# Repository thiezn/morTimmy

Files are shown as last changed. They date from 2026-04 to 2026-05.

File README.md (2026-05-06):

# mortimmy

`mortimmy` is a Rust robotics workspace for a small rover split across two runtime environments:

- `firmware/rp2350` for deterministic embedded control across two RP2350 board images: a motion-controller image for the Pimoroni Pico LiPo 2 and an audio-controller image for the Pico 2 W + Pico Audio Pack
- `host/mortimmy` for Raspberry Pi or macOS orchestration, transport bridging, telemetry, audio routing, and future camera control

The current hardware is:

- Raspberry Pi 3B V1.2
- Pimoroni Pico 2 W with Pico Audio Pack
- Pimoroni Pico LiPo 2
- Liquid Crystal Display LCM1602C V2.1
- 2x HC-SR04 ultrasonic ranger
- Adafruit 4-channel I2C-safe Bi-directional Logic Level Converter - BSS138
- Trellis M4 4x4 keypad and LED matrix

## Hardware

| Component | Version / Model | Purpose |
| --- | --- | --- |
| Raspberry Pi | 3B V1.2 | Main host computer running the daemon, USB device orchestration, telemetry, and higher-level coordination |
| Motion controller | Pimoroni Pico LiPo 2 (RP2350B) | USB-connected real-time controller for motors, sensors, the LCD status display, and future servo logic |
| Audio controller | Pico 2 W + Pico Audio Pack | USB-connected audio playback controller for the DAC and amp-enable path |
| Audio add-on | Pimoroni Pico Audio Pack | I2S DAC and headphone / line-out hardware mounted on the Pico 2 W |
| Character display | LCM1602C V2.1 | 16x2 local status display driven in 4-bit mode from the motion-controller Pico |
| Ultrasonic sensors | 2x HC-SR04 | Forward-left and forward-right distance measurement for obstacle awareness |
| Motor drivers | 2x L298N dual H-bridge | Drive four wheel motors from the motion controller GPIO |
| Wheel motors | 4x DC gear motors | Rover propulsion |
| Power regulator | UBEC / buck, 5 V 3 A | Regulates battery voltage down to the Raspberry Pi supply rail |
| Battery pack | 2x 18650, 2S | Main energy source for the rover |
| Keypad / LEDs | Trellis M4 4x4 | Future local input and status LED surface |
| 4-channel I2C-safe Bi-directional Logic Level Converter - BSS138 | Level shifting for HC-SR04 TRIG/ECHO wiring and future I2C peripherals |

Shared crates under `crates/` define the core types, driver traits, and the wire protocol used across both sides. The protocol uses `postcard` for serialization and a COBS-framed transport with CRC16 integrity checks so the same message contract can move over USB CDC, UART, and recorded capture files.

For the current ultrasonic path, the Adafruit BSS138 board should be treated as a four-channel signal translator, not as a power supply. It needs `3V3`, `5V`, and `GND` connected as reference rails, then one channel for `TRIG` and one for `ECHO` if you want a conservative 3.3 V to 5 V interface. That means one board cleanly supports two HC-SR04 modules; a third sensor only fits if you accept module-dependent direct 3.3 V triggering and reserve the board channels for `ECHO` only.

## Firmware Targets

The embedded workspace keeps one RP2350 crate and composes board-specific images with feature flags instead of cloning a second firmware crate. Each image owns its board profile, pin map, target directory, and deployment metadata.

| Deploy target | Board | Cargo feature | Target dir | Current scope |
| --- | --- | --- | --- | --- |
| `motion-controller` | Pimoroni Pico LiPo 2 | `board-motion-controller` | `target/mortimmy-rp2350-motion-controller` | USB CDC transport, L298N motor drive, HC-SR04 ranging, LCD1602 bring-up on GP20/GP21/GP22/GP26/GP27/GP28 |
| `audio-controller` | Pico 2 W + Pico Audio Pack | `board-audio-controller` | `target/mortimmy-rp2350-audio-controller` | USB CDC transport, Audio Pack bring-up seam on GP9-GP11 plus optional GP29 amp enable |

`mortimmy-tools deploy firmware ...` selects these metadata blocks with `--target motion-controller` or `--target audio-controller`. The CLI still defaults to `motion-controller` for backwards compatibility.

Detailed architecture notes live in [docs/src/architecture/architecture.md](docs/src/architecture/architecture.md). Protocol-specific notes live in [docs/src/architecture/protocol.md](docs/src/architecture/protocol.md). Open follow-up work lives in [TODO.md](TODO.md).

## Current Scope

The workspace now contains a compileable control-plane scaffold with test and tooling support:

- `mortimmy-core` defines shared units, limits, modes, and error types.
- `mortimmy-protocol` defines the postcard schema, typed control and telemetry messages, CRC16 checks, and a stream-oriented COBS frame decoder sized for the current audio-forwarding contract.
- `mortimmy-drivers` defines hardware-facing traits for motors, servos, ultrasonic sensors, audio output, and Trellis input/LED control.
- `mortimmy-rp2350` is the active embedded crate for both RP2350 controller boards using `embassy-rp`, `embassy-usb`, and `panic-probe`; it now splits board-owned runtime wiring by target while keeping one shared scaffold, protocol bridge, and deploy metadata surface.
- `mortimmy` provides `start` and `config` subcommands backed by a nested `config.toml` layout for serial, websocket, telemetry, audio, camera, and logging settings, and the `start` path now runs a keyboard-driven brain loop against either the loopback Pico scaffold or future live transports.
- `mortimmy-tools` can inspect and replay captured framed protocol streams, build host artifacts, and deploy RP2350 firmware through BOOTSEL or probe-rs workflows.
- `mortimmy-integration-test` provides the root integration harness for protocol roundtrips and future live hardware smoke tests.

## Workspace Layout

```text
.
├── Cargo.toml
├── README.md
├── TODO.md
├── crates/
│   ├── core/
│   ├── drivers/
│   └── protocol/
├── docs/
│   └── src/
│       └── architecture/
├── firmware/
│   └── rp2350/
├── host/
│   ├── mortimmy/
│   └── tools/
├── integration_test/
└── scripts/
```

## Prerequisites

- Rust toolchain from [rust-toolchain.toml](rust-toolchain.toml)
- `cargo`
- For docs: `mdbook` and `mdbook-mermaid`
- For embedded flashing and debugging: `cargo install probe-rs-tools --locked`
- For UF2 generation and BOOTSEL uploads: `cargo install elf2uf2-rs --locked`
- For BOOTSEL uploads over the RP2350 picoboot interface on macOS: `brew install picotool`

The pinned toolchain includes `thumbv8m.main-none-eabihf`, so a fresh `rustup` install is enough to build the active embedded target.

During development, you can invoke the deployment CLI directly from the workspace with `cargo run -p mortimmy-tools -- ...`. If you want a standalone binary on your `PATH`, install it from this checkout with `cargo install --path host/tools`.

## Build, Test, And Lint

Build the whole workspace:

```bash
cargo check --workspace
```

Validate both embedded images explicitly:

```bash
cargo build -p mortimmy-rp2350 --target thumbv8m.main-none-eabihf --no-default-features --features board-motion-controller --target-dir target/mortimmy-rp2350-motion-controller
cargo build -p mortimmy-rp2350 --target thumbv8m.main-none-eabihf --no-default-features --features board-audio-controller --target-dir target/mortimmy-rp2350-audio-controller
```

Or drive the same builds through the deployment metadata owned by the firmware crate:

```bash
cargo run -p mortimmy-tools -- deploy firmware build --target motion-controller
cargo run -p mortimmy-tools -- deploy firmware build --target audio-controller
```

Run tests and lints:

```bash
cargo test --workspace
cargo clippy --workspace --all-targets
```

Build the documentation site:

```bash
mdbook build docs
```

Optional coverage report:

```bash
./scripts/coverage.sh
./scripts/coverage.sh --html
```

## Firmware Bring-Up On macOS

The current RP2350 firmware can be smoke-tested without any attached peripherals. On the embedded target each image now starts the same Embassy USB CDC protocol bridge, then hands off to a board-specific runtime module for the actual pin map and peripheral ownership.

The motion-controller image owns the Pico LiPo 2 motor, ultrasonic, and LCD wiring. The audio-controller image now only reserves the Pico Audio Pack control pins and exposes the seam where the RP2350 I2S transport will be wired in next.

The shared protocol is now exercised inside the firmware crate as well: desired-state, parameter, audio, Trellis LED, status, and ping commands are applied to the firmware scaffold under unit tests, and the default audio chunk size is aligned across host planning, wire payload sizing, and firmware buffering.

Validate the firmware locally before touching hardware:

```bash
cargo test -p mortimmy-rp2350
cargo run -p mortimmy-tools -- deploy firmware uf2 --target motion-controller
cargo run -p mortimmy-tools -- deploy firmware uf2 --target audio-controller
```

Upload over plain USB with the Pico in BOOTSEL mode:

1. Hold the board's `BOOTSEL` button while connecting USB-C.
2. Wait for either a BOOTSEL volume such as `RP2350` or `RPI-RP2` to appear, or for `picotool info` to list an RP2350 BOOTSEL device.
3. Run:

```bash
cargo run -p mortimmy-tools -- deploy firmware uf2-deploy --target motion-controller
```

Swap `--target audio-controller` when you are working with the Pico 2 W image.

If `picotool` is installed, `mortimmy-tools deploy firmware uf2-deploy` prefers `picotool load -v -x -t uf2` and reboots the board directly. This is the recommended macOS path because mass-storage copies to the BOOTSEL volume have hung behind `storagekitd` on this machine. The tool falls back to copying `NEW.UF2` only when `picotool` cannot access the BOOTSEL interface.

This flow has been validated end to end on this machine. A successful BOOTSEL deploy reported `Loading into Flash ... 100%`, `Verifying Flash ... 100%`, `OK`, and `The device was rebooted to start the application.`

If the deploy command reports `Unable to find a board in BOOTSEL mode`, the board is not in BOOTSEL mode yet or neither the picoboot interface nor the BOOTSEL volume is visible to macOS. The tool now prints the exact BOOTSEL entry steps before exiting.

Flash and stream RTT logs through an SWD probe:

```bash
cargo run -p mortimmy-tools -- deploy firmware probe-list
cargo run -p mortimmy-tools -- deploy firmware flash --target motion-controller --probe-index 0
cargo run -p mortimmy-tools -- deploy firmware run --target motion-controller --probe-index 0
```

Use `--target audio-controller` with the same commands when debugging the Pico 2 W image.

The probe-based workflow uses the `probe-rs` chip name `RP235x`. A successful RTT session starts with a line like:

```text
boot board=Pimoroni Pico LiPo 2 mcu=RP2350B flash=16777216 psram=8388608 transport=usb-cdc mode=teleop audio=host-waveform-bridge chunk_samples=240 trellis=false ultrasonic=false battery=false
```

This path has now been validated on this machine with a Raspberry Pi Debug Probe after updating the probe firmware. `mortimmy-tools deploy firmware flash --probe-index 0 --verify` succeeds over SWD while the Pico LiPo 2 is not in BOOTSEL mode, so BOOTSEL is no longer required for normal flashing when the probe is attached.

If `mortimmy-tools deploy firmware run --probe-index 0` flashes successfully but shows no RTT or defmt output, rebuild with `DEFMT_LOG=info`. `defmt` filters logs at build time, and without that override the `info!` boot banner can be compiled out entirely. The provided VS Code build task below already sets `DEFMT_LOG=info` for you.

If `firmware-flash` reports `No debug probes were found`, attach an SWD-compatible debug probe or fall back to the BOOTSEL/UF2 path above.

After a successful BOOTSEL upload, the Pico should enumerate as a runtime USB CDC device such as `/dev/cu.usbmodem*` on macOS. That runtime enumeration path is implemented in firmware; regular live smoke coverage for the full host-to-device roundtrip remains tracked in `TODO.md`.

## Debug In VS Code

Install the VS Code extension `probe-rs.probe-rs-debugger` and keep `probe-rs` on your `PATH`.

This repo now ships a ready-to-use [launch.json](.vscode/launch.json) and [tasks.json](.vscode/tasks.json) for the motion-controller firmware. The default build task compiles the RP2350 ELF with `DEFMT_LOG=info` into the same `target/mortimmy-rp2350-motion-controller` directory used by the repo's deployment tooling. The audio-controller image uses the same crate and target triple, but it does not have a dedicated VS Code launch/task preset yet.

Typical flow:

1. Connect the Raspberry Pi Debug Probe to the Pico LiPo 2 over SWD.
2. Keep the Pico's normal USB connection attached if you also want the runtime CDC serial device on macOS.
3. In VS Code, run the default build task or press `F5` and choose `RP2350 Launch + RTT`.
4. Use `RP2350 Attach + RTT` when the firmware is already flashed and you want to attach without reflashing.

The launch configuration targets chip `RP235x`, uses `Swd`, flashes the ELF from `target/mortimmy-rp2350-motion-controller/thumbv8m.main-none-eabihf/debug/mortimmy-rp2350`, and enables RTT decoding for defmt channel 0. RTT output appears in the integrated terminal.

If you have more than one probe attached, add a `probe` field to [launch.json](.vscode/launch.json) using the `VID:PID:SERIAL` form shown by `cargo run -p mortimmy-tools -- deploy firmware probe-list`.

This repo does not currently ship a CMSIS-SVD file for RP235x, so the launch configuration omits `svdFile`. Source-level breakpoints, stepping, call stacks, locals, and defmt RTT logs still work without it.

## Run Locally On macOS

The host brain now supports both the `loopback` transport for local proofing and the `serial` transport for a live Pico USB CDC device. Both paths use the same routing, postcard codec, and CRC16 plus COBS framing.

`teleop` with zero drive is now the nominal stopped state. If the firmware link times out, the controller enters `fault`, resets to its safe failed state, and the host reasserts its last requested `teleop` or `autonomous` mode after reconnect.

Create or update a config file:

```bash
cargo run -p mortimmy -- config --config ./config.toml --print
```

Run the brain loop with keyboard input and the in-process Pico scaffold:

```bash
cargo run -p mortimmy -- start \
  --config ./tmp/brain-loopback.toml \
  --input-backend keyboard \
  --transport-backend loopback
```

Useful keyboard commands during bring-up:

```text
p | ping
x | stop
w | forward
s | reverse
a | left
d | right
t | teleop mode
u | autonomous mode (default servo-scan plan)
f | fault mode
q | quit
```

Switch the local keyboard to tank controls when you want per-tread input:

```bash
cargo run -p mortimmy -- start \
  --config ./tmp/brain-loopback.toml \
  --input-backend keyboard \
  --keyboard-drive-style tank \
  --transport-backend loopback
```

You can also press `m` while the session is running to toggle between `wasd` and `tank` driving. In tank mode, `w` and `s` control the left tread, `e` and `d` control the right tread, and `a` gives a left pivot shortcut by driving the left tread forward while reversing the right tread. To accept input from only one controller instead of letting the most recent controller win, pass `--controller-lock KIND:INSTANCE`, for example `--controller-lock keyboard:local`.

Websocket controllers are now live on the configured bind address as well. Each websocket client appears as its own `websocket:client-N` controller, so `--controller-lock websocket:client-1` will pin the brain to the first connected websocket client. Send JSON text frames such as:

```json
{"type":"control","drive":{"forward":1.0,"turn":0.0,"speed":300}}
{"type":"control","drive":null}
{"type":"command","command":"ping"}
{"type":"command","command":"teleop"}
```

`forward` and `turn` are normalized from `-1.0` to `1.0` and map onto the existing desired-state control path. Supported websocket commands are `ping`, `stop`, `teleop`, `autonomous`, `fault`, and `quit`.

This path has been validated on this machine with `p` followed by `q`; the host logged startup, encoded the ping command over the shared protocol, and received `telemetry pong: Pong` back from the firmware scaffold.

Run the same brain loop against a flashed Pico over USB CDC:

```bash
cargo run -p mortimmy -- start \
  --config ./tmp/brain-serial.toml \
  --input-backend keyboard \
  --transport-backend serial \
  --serial-device /dev/cu.usbmodem0001
```

For live hardware validation, `p` should return `telemetry pong: Pong`, holding `w` plus `a` should produce one combined desired-state control path, and `u` should switch the host into the built-in autonomous servo-scan plan until another mode is selected.

If you want to exercise the future camera seam, enable the optional `nokhwa` backend:

```bash
cargo run -p mortimmy --features camera-nokhwa -- start \
  --config ./config.toml \
  --serial-device /dev/tty.usbmodem0001 \
  --camera-enabled=true \
  --camera-backend nokhwa
```

Inspect or replay a captured protocol stream:

```bash
cargo run -p mortimmy-tools -- inspect ./captures/session.bin
cargo run -p mortimmy-tools -- replay ./captures/session.bin --dry-run
```

## Run On Raspberry Pi

The host daemon is intended to run directly on Raspberry Pi OS once the USB/serial bridge is wired to the firmware.

Build on the Pi:

```bash
cargo build -p mortimmy --release
```

Write or update the Pi config:

```bash
./target/release/mortimmy config --config ./config.toml \
  --serial-device /dev/ttyACM0 \
  --websocket-bind 0.0.0.0:9001 \
  --audio-enabled=true \
  --audio-backend firmware-bridge
```

Start the daemon:

```bash
./target/release/mortimmy start --config ./config.toml
```

Example config layout:

```toml
[serial]
device_path = "/dev/ttyACM0"
baud_rate = 115200

[websocket]
bind_address = "0.0.0.0:9001"

[telemetry]
publish_interval_ms = 100
queue_capacity = 256

[audio]
enabled = true
backend = "firmware-bridge"
sample_rate_hz = 24000
channels = 1
chunk_samples = 240
volume_percent = 100

[camera]
enabled = false
backend = "disabled"
device_index = 0
width = 640
height = 480
fps = 30

[logging]
level = "info"
no_color = false
```

## Integration Tests

The `integration_test` crate contains both portable protocol tests and ignored live-hardware smoke tests. Hardware tests are configured through the `MORTIMMY_HW_CONFIG` environment variable.

A checked-in bare-board sample lives at [integration_test/hardware.example.toml](integration_test/hardware.example.toml). It assumes no audio bridge or Trellis hardware is attached yet.

Example hardware test config:

```toml
serial_device = "/dev/ttyACM0"
baud_rate = 115200
timeout_ms = 2000
expect_audio_bridge = false
expect_trellis = false
```

Run the ignored live tests:

```bash
MORTIMMY_HW_CONFIG=./integration_test/hardware.example.toml cargo test -p mortimmy-integration-test -- --ignored
```

## Deployment CLI

The deployment surface now lives in `mortimmy-tools deploy`. The examples below use the installed binary name; if you are running straight from the workspace, prefix them with `cargo run -p mortimmy-tools --` instead.

Host workflows:

```bash
mortimmy-tools deploy host build
mortimmy-tools deploy host print-artifact
mortimmy-tools deploy host local-install --sudo
mortimmy-tools deploy host remote-copy --remote-host pi@raspberrypi.local
mortimmy-tools deploy host remote-install --remote-host pi@raspberrypi.local --sudo
```

Firmware workflows:

```bash
mortimmy-tools deploy firmware build --target motion-controller
mortimmy-tools deploy firmware build --target audio-controller
mortimmy-tools deploy firmware print-artifact --target audio-controller
mortimmy-tools deploy firmware uf2 --target audio-controller
mortimmy-tools deploy firmware uf2-deploy --target motion-controller
mortimmy-tools deploy firmware probe-list
mortimmy-tools deploy firmware flash --target motion-controller --probe-index 0
mortimmy-tools deploy firmware run --target motion-controller --probe-index 0
```

The most useful customization flags are:

- Global logging: `--log-level trace|debug|info|warn|error`, `--no-color`
- Host deployment: `--package`, `--bin`, `--profile`, `--install-dir`, `--remote-host`, `--remote-dir`
- Firmware build and UF2 packaging: `--target motion-controller|audio-controller`, `--profile`, `--output`
- Firmware probe workflows: `--probe-index`, `--protocol swd|jtag`, `--speed-khz`
- Firmware flashing behavior: `--chip-erase`, `--preverify`, `--verify`, `--restore-unwritten`, `--disable-double-buffering`

`mortimmy-tools deploy firmware uf2-deploy` prefers `picotool` when it can see the board in BOOTSEL mode and falls back to the mounted UF2 volume copy path only when the picoboot interface is unavailable. `mortimmy-tools deploy firmware run` currently delegates the monitor UX to `probe-rs run`, which preserves the existing defmt/RTT workflow while keeping the board-target selection inside the Rust deployment tool.

## Documentation

- Architecture: [docs/src/architecture/architecture.md](docs/src/architecture/architecture.md)
- Roadmap: [TODO.md](TODO.md)
- MdBook summary: [docs/src/SUMMARY.md](docs/src/SUMMARY.md)

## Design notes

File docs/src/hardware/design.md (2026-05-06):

# Hardware System Architecture and Power Design

## 1. System Architecture Overview

This robot is designed as a **layered hardware system**. Each layer has a clearly defined responsibility, explicit interfaces, and controlled dependencies. Power is treated as a first‑class subsystem rather than an afterthought.

### Layered Hardware Model

    Mechanical Structure
    └── Power System
        ├── High‑power actuation rails (motors)
        ├── Medium‑power actuation rails (servos)
        ├── Logic power rails (MCUs, SBCs, sensors)
    └── Compute & Control
        ├── Main processor (SBC / Raspberry Pi)
        ├── Real‑time controllers (microcontrollers)
    └── Interconnect
        ├── Power distribution
        ├── Data buses and signaling
    └── Peripherals
        ├── Motors
        ├── Servos
        ├── Sensors
        ├── Audio and UI components

Each layer may evolve independently as long as **power interfaces and signal contracts remain stable**.

## 2. Power Architecture

### Design Decision

The system uses **a single battery source with centralized power distribution**, implemented through a dedicated **Power Distribution Board (PDB)**

All primary system rails originate on this board.  
The only local conversion off-board is the Pico 2 onboard 3.3 V regulator, used only for control-board logic.

The control board feeds the Pico 2 at `VSYS` from `AUX_5V` through a reverse-blocking ideal-diode path. The Pi 3B still reaches the Pico over the Pico USB connector for programming and runtime communication.

### Power Topology

    Battery Pack (2S single source)
    │
    ├── Protected raw rail (`MOTOR_VM`)
    │   └── Two TB6612FNG motor-driver stages on the PDB
    │
    ├── Medium‑current rail (`SERVO_6V`)
    │   └── Servo connectors
    │
    └── Logic rails
        ├── `PI_5V` → Raspberry Pi
        ├── `AUX_5V` → Control board `VSYS` feed and 5 V loads
        ├── `DRV_3V3` → PDB-local TB6612 logic
        └── Pico `3V3` → Control-board MCU and level shifting

### Rail Separation Rationale

*   Motors generate electrical noise and large current spikes
*   Servos generate medium transient loads
*   Logic components require clean and stable voltage

Separating rails **prevents brown‑outs, resets, and signal corruption** while maintaining a shared reference ground.

## 3. Power Distribution Board (PDB)

### Role

The Power Distribution Board is the **electrical anchor** of the system.

It has no compute logic and performs no signaling functions beyond power delivery and monitoring.

### Core Responsibilities

*   Accept battery input
*   Provide reverse‑polarity and over‑current protection
*   Generate required voltage rails
*   Distribute power through dedicated connectors
*   Provide a central ground reference

### Typical Components on the PDB

*   Battery connector (JST-VH in the current board plan)
*   Main fuse
*   Master power switch
*   Reverse polarity protection (MOSFET or diode)
*   5.1 V buck converter for `PI_5V` and `AUX_5V`
*   6.0 V buck converter for `SERVO_6V`
*   Local 3.3 V regulator for TB6612FNG `VCC` and `STBY`
*   Two TB6612FNG stages on the PDB beside the wheel-motor connectors
*   Bulk capacitors near the battery entry, the 5.1 V rail, the 6.0 V rail, and each TB6612FNG stage
*   Measurement points for each rail
*   Ground plane with controlled high-current return paths and stitching vias around the driver region

## 4. System Architecture

                         ┌────────────────────┐
                         │    Battery Pack    │
                         └─────────┬──────────┘
                                   │
                        ┌──────────▼──────────┐
                        │ Power Distribution  │
                        │ Board (PDB)         │
                        │─────────────────────│
                        │ • Fuse              │
                        │ • Polarity protect  │
                        │ • TB6612FNG x2      │
                        │ • 6V Buck (Servos)  │
                        │ • 5.1V Buck         │
                        │ • DRV_3V3 Regulator │
                        │ • Central Ground    │
                        └───┬────────┬─────┬─┘
                            │        │     │
                    ┌───────▼──────┐ │     │
                    │ Control Board│ │     │
                    │ Pico + LCD + │ │     │
                    │ US + USB dev │ │     │
                    └──────────────┘ │     │
                                     │     │
                             ┌───────▼┐ ┌──▼─────────┐
                             │ Servos │ │ Raspberry  │
                             │ (6V)   │ │ Pi (5V)    │
                             └────────┘ └────────────┘

All components connect **inwards** to the power system rather than chaining power between devices.

## 5. Detailed Power Rail Schematic (Conceptual)

                    Battery (+)
                        │
                    [ Main Fuse ]
                        │
                   [ Master Switch ]
                        │
               [ Reverse Polarity Protection ]
                        │
                ┌────────┼──────────────┬──────────────┐
                │        │              │              │
          `MOTOR_VM`  [Buck 5.1V]   [Buck 6.0V]   [Reg 3.3V]
                │        │              │              │
         TB6612FNG x2  `PI_5V` +     Servo Rail    `DRV_3V3`
                    │       `AUX_5V`         │              │
            Wheel Motors  │            Servos      TB6612 VCC/STBY
                          │
                  Raspberry Pi + Control Board
                          │
                    `AUX_5V` -> ideal diode -> Pico `VSYS`
                    USB `D+`/`D-`/`VBUS` -> Pico USB connector

### Grounding Strategy

*   One **main ground bus** on the PDB
*   All rails return to this point
*   No daisy‑chained grounds
*   Sensitive logic grounds remain physically distant from motor current paths

## 6. Data and Interconnect Strategy

### Power and Data Separation

Power delivery and data signaling are always routed separately except where standards require otherwise (e.g. servo headers).

For the motion controller, keep USB as the primary Pi 3B to Pico 2 interface. The control board powers the Pico from `AUX_5V` into `VSYS`, while the Pi USB host connection still carries `D+`, `D-`, `GND`, shield, and host `VBUS` to the Pico USB connector for attach detect and programming.

### Data Buses

| Bus | Use Case | Pros | Cons |
| --- | --- | --- | --- |
| USB | Pi ↔ Pico | High bandwidth, power + data | Connector bulk, grounded noise path |
| UART | Pi ↔ Pico | Simple, deterministic | Point‑to‑point |
| I²C | Sensors | Minimal wiring | Noise sensitive, short distance |
| SPI | High‑speed peripherals | Fast, robust | More wires |
| CAN (future) | Distributed modules | Robust, fault tolerant | Extra transceivers |

### Forward obstacle sensing

The motion controller now owns a dual ultrasonic sensing pair built from two HC-SR04 modules.

*   One sensor is mounted forward-left at roughly 45 degrees.
*   One sensor is mounted forward-right at roughly 45 degrees.
*   Both sensors are powered from the 5V logic rail.
*   Both sensors share one Adafruit 4-channel BSS138 level converter.

The current pin and signal contract is:

*   GP14 / GP15: forward-left `TRIG` and `ECHO`
*   GP16 / GP17: forward-right `TRIG` and `ECHO`
*   The level converter uses all four BSS138 channels: left `TRIG`, left `ECHO`, right `TRIG`, right `ECHO`

The firmware polls the two HC-SR04 modules sequentially rather than simultaneously. That avoids overlapping trigger bursts and reduces acoustic crosstalk between the left and right forward cones.

## 7. Design Rules

These rules define the system’s long‑term robustness.

1.  Power generation occurs **only on the Power Distribution Board**
2.  Motors never share a rail with logic components
3.  Servos have their own dedicated voltage rail
4.  No cascaded regulators unless explicitly designed
5.  One shared ground with controlled return paths
6.  Every rail is measurable and fuseable
7.  Connectors are preferred over soldered wires
8.  Breadboards are prohibited for final power delivery
9.  Mechanical mounting and wiring paths are designed together
10. All connectors are keyed or polarized

## 8. Terminology Reference

| Term | Description |
| --- | --- |
| **Power Rail** | A regulated voltage supply distributed throughout the system |
| **Buck Converter** | A switching regulator that efficiently steps voltage down |
| **Regulator (LDO)** | Linear voltage regulator, low noise but inefficient |
| **Star Grounding** | Ground topology where all returns meet at one physical point |
| **Main Ground Bus** | Central low‑impedance ground reference on the PDB |
| **Dupont Wires** | Temporary jumper wires used only during prototyping |
| **Servo** | Actuator with control + power combined in a 3‑wire interface |
| **Motor Driver** | High‑current interface between logic signals and motors |
| **JST-VH / JST-XH** | Board and harness connectors used for power and signal wiring |
| **Power Distribution Board** | Dedicated PCB handling all system power |
| **Data Bus** | Shared signaling interface between devices |

## 9. Resulting System Properties

By enforcing this architecture, the system achieves:

*   Electrically stable operation
*   Modular expansion capability
*   Mechanical and electrical coherence
*   Predictable behavior under load
*   Clear separation of responsibilities
*   A maintainable and professional hardware platform

This design forms the foundation for future iterations, higher integration, and long‑term reliability.

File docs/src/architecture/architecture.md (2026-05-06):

# Architecture

## Overview

`mortimmy` is split into a small set of focused Rust packages with a hard boundary between deterministic embedded control and host-side orchestration.

- The RP2350B firmware owns real-time I/O, safety enforcement, audio output, and direct peripheral control.
- The Raspberry Pi host owns networking, routing, telemetry fanout, capture tooling, and optional camera integration.
- Shared crates carry the protocol, units, limits, and driver abstractions so both sides evolve against the same contract.

The codebase is organized as an implementation scaffold, and the package boundaries align with the active hardware direction: Pimoroni Pico LiPo 2, Pico Audio Pack, and Trellis M4 4x4.

The active control design is centered on a desired-state control plane:

- the host brain owns the latest desired mode, drive, and servo targets
- the firmware owns the latest applied control state and enforces safety locally
- one-shot actions such as controller status requests, parameter updates, audio chunks, and Trellis LED updates stay outside that continuous-control path

## Repository Layout

```text
.
├── Cargo.toml
├── crates/
│   ├── core/             # shared units, limits, modes, and errors
│   ├── drivers/          # hardware-facing traits used by embedded code
│   └── protocol/         # postcard schema, CRC policy, COBS framing, decoder
├── firmware/
│   └── rp2350/           # no_std firmware target for the Pimoroni Pico LiPo 2
├── host/
│   ├── mortimmy/         # runtime daemon for serial/USB, routing, telemetry, config
│   └── tools/            # capture inspection and replay tooling
├── integration_test/     # protocol and live-hardware integration harness
└── docs/
    └── src/
```

## Shared Crates

### `crates/core`

This crate provides the shared language for the rest of the workspace:

- `Mode` for robot operating states such as teleop, autonomous, and fault
- units such as millimeters, milliseconds, PWM ticks, and servo ticks
- safety-oriented defaults such as command timeout and motion limits
- common error types that can cross the firmware-host boundary

The goal is to keep protocol logic and driver traits free from duplicated constants or host-only assumptions.

### `crates/protocol`

The protocol crate defines the shared wire contract.

- Serialization uses `postcard` so the message layer stays compact and `no_std` friendly.
- Frame transport uses CRC16 plus COBS encoding so framed packets can survive arbitrary zero bytes on USB CDC, UART, and captured byte streams.
- `FrameDecoder` provides stream-oriented resynchronization at the byte level for host tools and serial/USB bridges.

Message families include:

- `messages::host` for latest-wins control and correlated request envelopes from the brain
- `messages::commands` for desired-state, parameter, audio, and Trellis payloads reused inside those envelopes
- `messages::controller` for response, report, and event envelopes emitted by the controller
- `messages::telemetry` for controller status, control-applied state, range, battery, audio status, and Trellis event payload types
- `WireMessage` as the top-level direction tag shared by both sides of the link

The shared protocol page at [protocol.md](protocol.md) documents the framing contract and message surface in more detail.

### `crates/drivers`

Driver traits define the embedded-facing APIs for the first hardware layer:

- motor control
- servo positioning
- ultrasonic distance sensing
- audio output
- Trellis keypad and LED matrix interaction

These traits stay intentionally small so the real firmware can depend on trait contracts rather than concrete board wiring.

## Embedded Firmware

The active firmware target is `firmware/rp2350` and is built around the Embassy ecosystem.

- `embassy-rp` provides the RP2350B integration layer with the `rp235xb` feature enabled.
- `embassy-usb` provides the runtime USB CDC transport used by the live serial path.
- `panic-probe` is used from the start so embedded panics remain debugger-friendly.
- `defmt` and `defmt-rtt` are included for compact embedded logging and RTT inspection.

The crate centers around a `FirmwareScaffold` that aggregates:

- board profile information for the Pimoroni Pico LiPo 2
- control-loop and safety state
- link receive and transmit task placeholders
- sensor sampling task placeholders
- USB transport scaffolding
- audio output state for the Pico Audio Pack
- Trellis keypad and LED state for the Trellis M4 4x4
- direct protocol command application and telemetry snapshot helpers for host-free unit testing
- a deterministic bring-up report that is emitted over `defmt` during boot and reused by host-side tests

The embedded control plane has a single latest-wins apply path for continuous motion:

- `ControlLoop::apply_desired_state` applies mode, drive, and servo together
- stale motion still times out in firmware, even if the host misbehaves
- one-shot commands stay outside that continuous-control path

### Board Profile

The embedded board profile encodes the repository's active target assumptions:

- board: Pimoroni Pico LiPo 2
- MCU: RP2350B
- flash: 16 MiB
- PSRAM: 8 MiB
- built-in USB-C, Qw/ST, and LiPo charging support

### Embedded Safety Model

The safety model remains firmware-first:

- motors start disabled
- stale commands should stop motion quickly
- the MCU remains the final enforcement point for limits even if the host clamps first
- board bring-up for audio and Trellis should not weaken the core motion-safety path

`stationary teleop` is the normal stopped state, while `fault` is reserved for safety failures and explicit fault requests.

- a desired state with zero drive leaves the robot in `teleop` with zero motor output
- link timeout or another safety failure resets the scaffold and enters `fault`
- when the host reconnects, it reasserts its last requested `teleop` or `autonomous` mode

### Bring-Up And Debug Path

- `.cargo/config.toml` links the RP2350 build with `link.x`, `defmt.x`, and `--nmagic` so the generated ELF is directly usable by probe-rs tooling and UF2 conversion.
- `firmware/rp2350/memory.x` encodes the active Pico LiPo 2 memory map: 16 MiB XIP flash at `0x10000000` and 520 KiB SRAM at `0x20000000`.
- `firmware/rp2350/build.rs` copies `memory.x` into the linker search path so repo-root workspace builds produce the same valid image as crate-local builds.
- `mortimmy-tools deploy firmware` covers the full bring-up loop: build ELF, print artifacts, convert to UF2, deploy through `picotool` when the RP2350 BOOTSEL interface is visible, fall back to a BOOTSEL-mounted Pico volume when it is not, flash through the native `probe-rs` library, and hand off defmt/RTT monitoring to `probe-rs run`.
- The boot path is intentionally safe for bench testing without peripherals: it logs the board profile and default task state, then waits in a safe zero-drive `teleop` state for desired-state traffic.
- A successful USB-only BOOTSEL upload boots into the runtime USB CDC path; the host can then reconnect over the normal serial backend once the device enumerates.

## Host Runtime

The main host runtime is `host/mortimmy`. It runs as a normal `std` Rust program and owns the system integration work that does not belong on the microcontroller.

Subsystem seams:

- `cli` provides `start` and `config` subcommands
- `config` loads and persists a nested TOML config file
- `brain` owns the high-level robot loop, transport selection, and telemetry handling
- `brain::autonomy` provides a safe hardcoded autonomous runner that already uses desired-state sequencing
- `input` converts operator backends such as the keyboard into shared high-level brain commands
- `routing` clamps and validates outbound commands against shared limits
- `serial`, `telemetry`, and `websocket` define the transport and fanout boundaries
- `audio` plans waveform chunking for the firmware bridge
- `camera` provides the optional `nokhwa` seam for Linux and macOS camera backends

The host runtime stack is intentionally conventional:

- `tokio` for async execution
- `tokio-tungstenite` for WebSocket support
- `tokio-serial` for serial I/O
- `tracing` and `tracing-subscriber` for logs

The `loopback` transport backend reuses the same host framing code as the live `serial` path, but exchanges bytes with `FirmwareScaffold` in-process so protocol work can be exercised when hardware is not attached or not in BOOTSEL mode.

The host transport contract separates three responsibilities on the same USB CDC link:

- `send_control` for latest-wins control snapshots
- `send_request` for correlated one-shot request/response traffic
- `drain_messages` for controller-originated reports and events that can arrive independently of requests

## Desired-State Brain Model

The host brain owns a single desired snapshot:

- desired mode
- desired drive intent
- desired servo target

Keyboard input mutates that desired snapshot in teleop mode. Autonomous mode mutates it through a small step runner with explicit step conditions. The runner ships with a safe default servo-scan plan so autonomous mode exercises sequencing without commanding blind drive motion.

On transport loss, the controller times out into `fault` and resets to a safe failed state. The host keeps the last requested mode and reasserts it on reconnect.

That split is deliberate:

- runtime robot behavior is modeled as a runtime state machine because the mode can change based on user input, reconnects, telemetry, and injected host commands
- typestate is used more selectively for driver initialization, builder-style setup, and API contracts that must be impossible to misuse at compile time

## Autonomy Flow

```mermaid
sequenceDiagram
  participant Operator as Operator or WebSocket Client
  participant Brain as RobotBrain
  participant Runner as AutonomyRunner
  participant FW as Firmware ControlLoop

  Operator->>Brain: SetMode(Autonomous)
  Brain->>Runner: reset()
  Brain->>Runner: target_at(now)
  Runner-->>Brain: AutonomousTarget
  Brain->>FW: HostMessage::Control(generation, desired_state)
  FW-->>Brain: ControllerMessage::Report(ControlAppliedReport)
  loop while autonomous
    Brain->>Runner: target_at(now)
    Runner-->>Brain: next target when condition elapsed
    Brain->>FW: HostMessage::Control(generation, desired_state)
    FW-->>Brain: ControllerMessage::Report(ControlAppliedReport)
  end
  Operator->>Brain: SetMode(Teleop or Fault)
  Brain->>Runner: reset()
```

## Typestate And State Machines

The embedded Rust typestate pattern is important, but it is not applied uniformly.

- Use typestate for configuration and ownership boundaries where an invalid sequence should not compile.
- Use runtime enums and explicit transition functions for robot modes, autonomy plans, and control-loop state that must react to live input and telemetry.
- Keep driver traits small and stateful helpers explicit so firmware code can apply one desired state through one owner rather than through many partially overlapping methods.

This keeps compile-time guarantees where they help most without forcing dynamic robot behavior into a compile-time shape that would be hard to evolve once websocket-driven autonomy arrives.

## Operational Tools

`host/tools` is shaped around the same shared protocol rather than placeholder logging only.

- `inspect` parses a recorded capture and reports frame and message counts using the real framing decoder
- `replay` reuses the same capture parsing path and serves as the live replay bridge seam for hardware testing

This keeps host operations, test fixtures, and the runtime transport all tied to the same wire contract.

## Integration Harness

The root `integration_test` crate exists to keep integration coverage separate from unit-level crates.

- portable protocol roundtrip tests validate the postcard plus COBS framing contract
- ignored smoke tests define the shape of live USB/audio/Trellis checks
- `MORTIMMY_HW_CONFIG` allows live hardware runs to load a serial device and capability expectations without hard-coding them into the test suite
- a checked-in sample hardware config at `integration_test/hardware.example.toml` gives the no-peripheral Pico bring-up flow a stable starting point

## End-To-End Flow

The intended runtime path is:

1. A local operator, autonomous runner, or websocket client updates the host-owned desired state.
2. The host validates and clamps that desired state against shared limits.
3. The host serializes the snapshot with `postcard`, wraps it with CRC16 plus COBS framing, and forwards it over the selected transport backend.
4. The firmware verifies the frame, applies the latest desired state, and enforces safety locally.
5. Controller status responses, control-applied reports, sensor reports, and controller events flow back through the same shared protocol to the host.
6. The host fans telemetry out to WebSocket clients and tooling or replay pipelines.

```mermaid
flowchart LR
  subgraph WS[Remote Clients]
    UI[Web UI or Controller]
    AUTO[Autonomy Process]
  end

  subgraph HOST[Brain]
    API[WebSocket Layer]
    AUTORUNNER[Autonomy Runner]
    ROUTER[Desired-State Routing and Validation]
    AUDIO[Audio Planner]
    BRIDGE[Serial or USB Bridge]
    CAMERA[Optional Camera Backend]
    TOOLS[Inspect and Replay Tools]
  end

  subgraph MCU[RP2350B Firmware]
    RX[Link RX]
    CTRL[Latest-Wins Control Loop]
    IO[Drivers and Sensors]
    AUDIOOUT[Pico Audio Pack]
    TRELLIS[Trellis M4]
    TX[Link TX]
  end

  UI --> API
  AUTO --> API
  API --> ROUTER --> AUDIO --> BRIDGE --> RX
  ROUTER --> AUTORUNNER
  RX --> CTRL --> IO
  CTRL --> AUDIOOUT
  CTRL --> TRELLIS
  IO --> TX --> BRIDGE
  CAMERA --> API
  TOOLS --> BRIDGE
```

## Operational Notes

- The host daemon is intended to run locally on macOS for development and directly on Raspberry Pi for deployment.
- The active embedded target is checked with `thumbv8m.main-none-eabihf` through the pinned toolchain.
- RP2350 firmware can be exercised either through a BOOTSEL UF2 upload, preferably via `picotool` on macOS, or through probe-rs with chip `RP235x` when a debug probe is attached.
- The host `start` command supports both loopback and live USB CDC serial transports.
- The RP2350 firmware includes an Embassy USB CDC executor task that applies framed host messages through `FirmwareScaffold` and emits controller messages.
- Continuous control flows through `HostMessage::Control`, and the host runs a built-in autonomous servo-scan plan when autonomous mode is selected.
- Documentation is built from `docs/src/` with `mdbook build docs`.

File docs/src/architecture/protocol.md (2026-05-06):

# Protocol

The shared protocol is the contract between the Raspberry Pi host and the RP2350 firmware.

## Goals

- Keep the wire format `no_std` friendly so the same types compile on both host and firmware.
- Keep transport framing resilient to arbitrary byte streams over USB CDC, UART, and recorded captures.
- Keep continuous control idempotent so firmware can apply the latest intent safely even when messages are retried or interleaved with one-shot actions.

## Transport

- Message payloads are serialized with `postcard`.
- Each payload is wrapped with a small header containing protocol version, sequence number, and payload length.
- A CRC16 protects the header plus payload.
- The resulting bytes are COBS-encoded and terminated with a zero delimiter.

This lets the host and firmware recover from partial reads, framing loss, and captured-stream replay without introducing heap allocation.

The protocol runs in two concrete bring-up modes:

- loopback, where the host exchanges framed bytes with `FirmwareScaffold` in-process
- live USB CDC, where the RP2350 Embassy task reads framed bytes from the CDC ACM class and writes controller messages back to the host serial backend

The Rust API is grouped the same way:

- `mortimmy_protocol::messages::host` contains host-originated control and request envelopes
- `mortimmy_protocol::messages::commands` contains reusable desired-state, parameter, audio, and Trellis payload types
- `mortimmy_protocol::messages::controller` contains controller-originated response, report, and event envelopes
- `mortimmy_protocol::messages::telemetry` contains the reusable controller status, control-applied, range, battery, audio, and keypad payload types

## Message Families

Host-to-firmware traffic is split into two semantic families:

- latest-wins control through `HostMessage::Control`
- correlated one-shot requests through `HostMessage::Request`

The continuous-control envelope includes:

- `generation`
- a full desired-state snapshot containing `mode`, `drive`, and `servo`

The host owns that snapshot and resends it while continuous control is active. The firmware treats it as latest-wins state rather than as a queue of imperative motion commands.

Host-to-firmware command coverage therefore includes:

- full desired-state updates for teleop and autonomous control
- explicit controller status requests through `GetControllerStatus`
- typed parameter updates for safety limits and subsystem tuning
- audio chunk forwarding for the Pico Audio Pack
- Trellis LED updates
- report cadence configuration through `ConfigureReports`

Controller-to-host traffic is split into three semantic families:

- `ControllerMessage::Response` for correlated replies to host requests
- `ControllerMessage::Report` for decoupled controller-originated data with independent cadence
- `ControllerMessage::Event` for immediate controller-originated events

The main controller data products are:

- `ControllerStatus`, returned as a request response and scoped to controller identity and health only
- `ControlAppliedReport`, emitted as a report with applied mode, drive state, servo state, last control-plane error, and the last applied control `generation`
- range and battery measurements as dedicated reports
- audio queue state as a dedicated report or request response
- Trellis pad input as a controller event

Status snapshots do not embed range data, and control-applied reports do not duplicate sensor snapshots. Sensor data has its own report path.

## Why Full Desired State messages?

The control message is intentionally a full message rather than a field patch.

- The payload is small enough for postcard plus COBS framing over USB CDC.
- A full snapshot keeps merge semantics trivial: the firmware only needs to remember the latest desired state.
- `teleop + zero drive` stays distinct from `fault`, which owns timeout and safe-stop recovery.
- Tests can assert one idempotent apply path instead of reasoning about ordering between `SetMode`, `Drive`, `Servo`, and `Stop`.

For this control surface, the full-snapshot model keeps merge semantics simple and safe.

## Teleop Sequence

```mermaid
sequenceDiagram
	participant Input as Keyboard Input
	participant Brain as RobotBrain
	participant Bridge as Serial Bridge
	participant FW as Firmware ControlLoop

	Input->>Brain: ControlState { drive = forward + left }
	Brain->>Brain: Merge into desired state
	Brain->>Bridge: HostMessage::Control(generation, desired_state)
	Bridge->>FW: WireMessage::Host(...)
	FW->>FW: apply_desired_state(latest wins)
	FW-->>Bridge: ControllerMessage::Report(ControlAppliedReport)
	Bridge-->>Brain: ControlAppliedReport
```

## Status Request Sequence

Status reads are explicit correlated requests rather than being coupled to control acknowledgements.

```mermaid
sequenceDiagram
	participant Brain as RobotBrain
	participant FW as Firmware

	Brain->>FW: HostMessage::Request(request_id, GetControllerStatus)
	FW-->>Brain: ControllerMessage::Response(request_id, ControllerStatus)
	FW-->>Brain: ControllerMessage::Report(Range or Battery) %% may interleave independently
```

## Audio Chunk Contract

The default host and firmware chunk size is `240` PCM samples. The protocol payload ceiling is sized so that one default chunk can be serialized and framed without an additional fragmentation layer.

That alignment matters because the host audio planner, firmware audio queue, and wire contract all need to agree on the same chunk size before live audio forwarding is possible.

## Firmware Integration

The firmware scaffold applies protocol traffic directly into the control, audio, Trellis, and sensor task state.

Continuous control has a single apply path:

- `ControlLoop::apply_desired_state` owns the combined mode, drive, and servo update
- `FirmwareScaffold::handle_host_message` maps host control traffic into that path and emits `ControlAppliedReport`
- the latest desired state replaces the previous desired state instead of stacking multiple motion commands

- limit-related parameter updates change the embedded control loop and watchdog budget
- audio and Trellis parameter updates reconfigure the corresponding scaffold tasks
- correlated requests emit explicit controller responses
- range, battery, audio queue state, and controller-originated data use dedicated report or event paths instead of being embedded into status snapshots
- invalid control data is surfaced as `CoreError::InvalidCommand` in the corresponding response or control-applied report

`FirmwareScaffold` is the shared apply surface used by unit tests and the live USB CDC runtime, so the protocol is executable inside the firmware crate rather than existing only as schema definitions.

On the host side, the keyboard backend and autonomous runner drive this same protocol path through the brain loop. Sustained control is expressed as one desired snapshot rather than a sequence of imperative motion messages.

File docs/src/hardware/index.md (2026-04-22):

# Hardware

This section covers the current robot hardware from three angles:

- [Design](design.md): system architecture, power distribution, and design rules.
- [Components](components.md): concrete parts in use, with one page per component.
- [Wiring](schematics/wiring.md): the generated wiring diagram and related schematic outputs.

The goal is to keep high-level rationale, part-level documentation, and concrete wiring artifacts separate but cross-linked.

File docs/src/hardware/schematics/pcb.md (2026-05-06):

# PCB designs

The hardware is split into two boards:

- A Power Distribution Board (PDB) that handles battery input protection, rail generation, the two TB6612FNG stages, wheel-motor outputs, indicators, and test points.
- A control board that carries the Pico 2, the HC-SR04 level shifting, the LCD and servo connectors, and the low-current control harness back to the PDB.

## Fixed design choices

- The wheel motors run from protected raw 2S battery voltage on `MOTOR_VM`. There is no motor buck stage and no motor-source selection jumper.
- The two TB6612FNG stages live on the PDB and are driven from the control board through a single 14-pin JST-XH control harness.
- The PDB generates `AUX_5V` for logic-side 5 V loads, `SERVO_6V` for both servos, and a local-only `DRV_3V3` rail for the TB6612FNG `VCC` pins and the shared `STBY` pull-up.
- The control board powers the Pico 2 from `AUX_5V` into `VSYS` through a reverse-blocking ideal-diode power path. Do not tie `AUX_5V` directly into the Pico `VBUS` pin.
- The control board derives two local 5 V branches from `AUX_5V`: `PICO_VSYS` for the Pico 2 and `5V_FILT` for the LCD and HC-SR04 connectors. The Pico-generated `3V3` rail remains the only control-board 3.3 V rail.
- The Raspberry Pi 3B keeps its link to the motion-controller Pico over the Pico USB connector. USB `D+`, `D-`, `GND`, `SHELL`, and host `VBUS` stay on the USB cable for device attach and programming, but `VBUS` is not the primary board power path.
- Use `0603` as the default footprint for small passives: resistors, indicator LEDs, pull-ups, 100 nF ceramics, and the 5 V ferrite bead.
- Use JST-VH for battery, board-to-board power, motor, and servo connectors.
- Use JST-XH for the HC-SR04 and LCD harnesses.

## Board architecture

- Keep all battery, buck-converter, servo, and motor-current loops on the PDB.
- Use only two interconnects between boards: one 4-pin JST-VH power harness and one 14-pin JST-XH driver-control harness.
- Keep the control board free of raw battery and motor current so the Pico, ultrasonic inputs, and LCD bus stay on the quieter board.
- Place the TB6612FNG stages beside the wheel-motor connectors so each high-current loop remains short.

## PCB defaults

- Use 2-layer FR-4 for both boards.
- Use 2 oz copper on the PDB. Use 1 oz copper on the control board.
- Keep all battery, motor, and servo traces wide and short. Keep the TB6612FNG stages on the PDB edge nearest the motor connectors.
- Use a continuous ground reference on both boards, but keep motor return current out of the sensor and LCD area.
- Add ground stitching vias anywhere the high-current ground path changes layer, around each TB6612FNG ground region, and beside the board-to-board ground pins.

## Power Distribution Board

### High-level overview

- Route `J_BAT` through the blade fuse, the master switch, the reverse-polarity MOSFET stage, and the battery-side TVS clamp. Treat the protected output as `VBAT_PROT`.
- Feed `MOTOR_VM` directly from `VBAT_PROT`. Place a 470 uF low-ESR capacitor at the protected battery entry and one `220 uF + 100 nF` decoupling set at each TB6612FNG stage.
- Generate one 5.1 V buck output and split it into an `AUX_5V` branch for the control board and a protected `PI_5V` branch for the Raspberry Pi connector.
- Put a resettable fuse or current-limited load switch in series with `PI_5V`, and place at least 100 uF bulk capacitance directly beside `J_PI_PWR`.
- Generate `SERVO_6V` with its own buck converter and keep the servo rail separate from `AUX_5V` all the way to the control-board harness.
- Generate a local `DRV_3V3` rail on the PDB only. Use it for both TB6612FNG `VCC` pins and the shared `STBY` pull-up; do not export this rail off-board.
- Fit one 100 nF ceramic directly across each wheel-motor terminal pair at the motor body.
- Add LED indicators and test points for `VBAT`, `VBAT_PROT`, `MOTOR_VM`, `AUX_5V`, `PI_5V`, and `SERVO_6V`, plus test access to `DRV_3V3` and `STBY`.

### PDB connector plan

| Ref | Connector | Family | Pinout | Notes |
| --- | --- | --- | --- | --- |
| `J_BAT` | Battery input | JST-VH 2-pin | `VBAT`, `GND` | Battery holder to PDB |
| `J_CTRL_AUX` | Control-board logic and servo feed | JST-VH 4-pin | `AUX_5V`, `SERVO_6V`, `GND`, `GND` | `AUX_5V` stays separate from `SERVO_6V`; local 5 V filtering happens on the control board |
| `J_CTRL_DRV` | Control-board driver control | JST-XH 14-pin | See motor-control harness pin map below | Single low-current harness for both TB6612FNG stages |
| `J_PI_PWR` | Raspberry Pi power | JST-VH 2-pin | `PI_5V`, `GND` | Dedicated Pi feed with its own current limiting |
| `J_MOTOR_FL` | Front-left motor | JST-VH 2-pin | `A01`, `A02` | Front-left wheel motor output |
| `J_MOTOR_RL` | Rear-left motor | JST-VH 2-pin | `B01`, `B02` | Rear-left wheel motor output |
| `J_MOTOR_FR` | Front-right motor | JST-VH 2-pin | `A01`, `A02` | Front-right wheel motor output |
| `J_MOTOR_RR` | Rear-right motor | JST-VH 2-pin | `B01`, `B02` | Rear-right wheel motor output |

### Motor-control harness pin map

| Pin | Net | Pico 2 GPIO | PDB destination | Notes |
| --- | --- | --- | --- | --- |
| 1 | `GND` | `GND` | Ground reference | Left-stage return and harness shield point |
| 2 | `L_PWMA` | `GP2` | Left TB6612FNG `PWMA` | Front-left speed command |
| 3 | `L_AIN1` | `GP3` | Left TB6612FNG `AIN1` | Front-left direction A |
| 4 | `L_AIN2` | `GP4` | Left TB6612FNG `AIN2` | Front-left direction B |
| 5 | `L_BIN1` | `GP5` | Left TB6612FNG `BIN1` | Rear-left direction A |
| 6 | `L_BIN2` | `GP6` | Left TB6612FNG `BIN2` | Rear-left direction B |
| 7 | `L_PWMB` | `GP7` | Left TB6612FNG `PWMB` | Rear-left speed command |
| 8 | `GND` | `GND` | Ground reference | Right-stage return and harness shield point |
| 9 | `R_PWMA` | `GP8` | Right TB6612FNG `PWMA` | Front-right speed command |
| 10 | `R_AIN1` | `GP9` | Right TB6612FNG `AIN1` | Front-right direction A |
| 11 | `R_AIN2` | `GP10` | Right TB6612FNG `AIN2` | Front-right direction B |
| 12 | `R_BIN1` | `GP11` | Right TB6612FNG `BIN1` | Rear-right direction A |
| 13 | `R_BIN2` | `GP12` | Right TB6612FNG `BIN2` | Rear-right direction B |
| 14 | `R_PWMB` | `GP13` | Right TB6612FNG `PWMB` | Rear-right speed command |

### PDB bill of material

| Qty | Item | Suggested value or spec | Notes |
| --- | --- | --- | --- |
| 1 | Battery input connector | JST-VH 2-pin, vertical or right-angle to suit layout | Mates with the battery-holder harness |
| 1 | Main fuse holder plus fuse | PCB fuse holder plus 7.5 A blade fuse | Protects the full robot supply |
| 1 | Master power switch | Latching SPST, at least 10 A DC | Full system power disconnect |
| 1 | Reverse-polarity protection stage | Ideal-diode MOSFET stage or equivalent controller plus MOSFET | Prevents battery reversal damage |
| 1 | Battery TVS diode | Unidirectional TVS for a 2S Li-ion rail | Clamps hot-plug and wiring transients |
| 1 | 5.1 V buck converter | 5 A minimum, low-ripple synchronous buck module or proven regulator stage | Source for both `AUX_5V` and the protected `PI_5V` branch |
| 1 | Raspberry Pi output protection stage | Resettable fuse or eFuse/current-limited load switch sized for the Pi 3B supply | In series with `PI_5V` |
| 1 | 6.0 V servo buck converter | 5 A peak minimum | Keeps servo surge current off the logic rail |
| 1 | 3.3 V driver logic regulator | Small LDO or regulator, about 150 mA or higher | Local-only `DRV_3V3` for both TB6612FNG `VCC` pins and the `STBY` pull-up |
| 2 | TB6612FNG motor-driver stages | One left and one right | Mount on the PDB beside the motor connectors |
| 1 | `STBY` pull-up resistor | 10 kOhm, 0603, to local `3V3` | Enables both TB6612FNG stages by default |
| 1 | `STBY` test pad or solder jumper | Normally left enabled | Useful during bring-up and fault isolation |
| 1 | Battery-input bulk capacitor | 470 uF low-ESR, 16 V or higher | Close to the protected battery entry |
| 1 | 5.1 V source bulk capacitor | 470 uF low-ESR, 10 V or higher | Close to the 5.1 V buck output before the branch split |
| 1 | Raspberry Pi connector bulk capacitor | 100 uF or higher, low-ESR, 10 V or higher | Close to `J_PI_PWR` after the protection stage |
| 1 | 6.0 V rail bulk capacitor | 470 uF low-ESR, 10 V or higher | Close to the 6.0 V buck output |
| 2 | Driver VM bulk capacitors | 220 uF low-ESR, 16 V or higher, one per TB6612FNG stage | Local motor surge reservoir on `MOTOR_VM` |
| 2 | Driver VM ceramic capacitors | 100 nF, 0603, one per driver | Place directly at each TB6612FNG `VM` pin |
| 2 | Driver VCC ceramic capacitors | 100 nF, 0603, one per driver | Place directly at each TB6612FNG `VCC` pin |
| 4 | Miscellaneous ceramic capacitors | 100 nF, 0603 | Battery entry, buck/regulator bypassing, and connector-side local bypassing |
| 6 | Rail indicator LEDs | 0603 | `VBAT`, `VBAT_PROT`, `MOTOR_VM`, `AUX_5V`, `PI_5V`, and `SERVO_6V` |
| 6 | LED resistors | 2.2 kOhm, 0603 | One per indicator LED |
| 1 | Control-board auxiliary connector | JST-VH 4-pin | `AUX_5V`, `SERVO_6V`, `GND`, `GND` |
| 1 | Control-board driver-control connector | JST-XH 14-pin | Single low-current control harness |
| 1 | Raspberry Pi power connector | JST-VH 2-pin | Dedicated Pi feed |
| 4 | Motor connectors | JST-VH 2-pin | One connector per wheel motor |
| 11 | Test points | `VBAT`, `VBAT_PROT`, `MOTOR_VM`, `AUX_5V`, `PI_5V`, `SERVO_6V`, `DRV_3V3`, `STBY`, and three grounds | Bring-up and troubleshooting |

## Control board

### High-level overview

- Mount the Raspberry Pi Pico 2 directly on the board and keep its USB connector accessible for programming and Raspberry Pi USB data.
- Bring `AUX_5V`, `SERVO_6V`, and two grounds in through `J_PWR_AUX`.
- Split `AUX_5V` into two local branches: `AUX_5V` -> reverse-blocking ideal-diode stage -> `PICO_VSYS`, and `AUX_5V` -> input bulk capacitor -> ferrite bead -> `5V_FILT`.
- Place `47 uF + 100 nF` directly after the ferrite bead and feed the LCD and both HC-SR04 connectors from `5V_FILT`.
- Feed the Pico 2 only at `VSYS` from `PICO_VSYS` and use the Pico-generated `3V3` rail as the only control-board 3.3 V rail.
- Keep the Pi 3B link as the Pico's native USB device connection. Leave USB `VBUS` on the USB connector for attach detect and programming, but do not short USB `VBUS` to `AUX_5V`, `5V_FILT`, or `PICO_VSYS`.
- Keep the HC-SR04 level shifting on the control board beside the Pico and the sensor connectors, and place one 100 nF ceramic directly at each HC-SR04 connector.
- Send all wheel-motor control signals to the PDB through the single 14-pin JST-XH harness using the fixed `GP2` through `GP13` mapping shown above.
- Use JST-VH for servo outputs and JST-XH for the HC-SR04, LCD, and PDB driver-control harnesses.
- Keep the control harness away from the ultrasonic echo lines where practical.

### Control-board connector plan

| Ref | Connector | Family | Pinout | Notes |
| --- | --- | --- | --- | --- |
| `J_PWR_AUX` | PDB auxiliary input | JST-VH 4-pin | `AUX_5V`, `SERVO_6V`, `GND`, `GND` | Logic and servo supply feed |
| `J_DRV_CTRL` | PDB driver control | JST-XH 14-pin | See motor-control harness pin map above | Single low-current control harness to the PDB |
| `J_SERVO_PAN` | Pan servo | JST-VH 3-pin | `PWM`, `SERVO_6V`, `GND` | Robust 3-wire servo harness |
| `J_SERVO_TILT` | Tilt servo | JST-VH 3-pin | `PWM`, `SERVO_6V`, `GND` | Robust 3-wire servo harness |
| `J_US1` | Forward-left HC-SR04 | JST-XH 4-pin | `5V`, `TRIG`, `ECHO`, `GND` | Sensor harness |
| `J_US2` | Forward-right HC-SR04 | JST-XH 4-pin | `5V`, `TRIG`, `ECHO`, `GND` | Sensor harness |
| `J_LCD` | LCD1602 harness | JST-XH 12-pin | `VSS`, `VDD`, `VO`, `RS`, `RW`, `E`, `D4`, `D5`, `D6`, `D7`, `LEDA`, `LEDK` | Leaves `D0` to `D3` unconnected |

### Control-board bill of material

| Qty | Item | Suggested value or spec | Notes |
| --- | --- | --- | --- |
| 1 | Raspberry Pi Pico 2 footprint | Direct-solder Pico 2, no socket | Keep the USB connector mechanically accessible |
| 1 | Input bulk capacitor before ferrite | 100 uF, 10 V or higher | Place at `J_PWR_AUX` on the incoming `AUX_5V` rail |
| 1 | Pico `VSYS` ideal-diode stage | Reverse-blocking ideal diode or PFET-based ideal-diode circuit sized for Pico current | Feeds `PICO_VSYS` from `AUX_5V` without backfeeding the board from USB `VBUS` |
| 1 | Ferrite bead on `AUX_5V` input | 0603 ferrite bead sized for the LCD and HC-SR04 current | Forms the `5V_FILT` branch |
| 1 | Filtered 5 V bulk capacitor | 47 uF, 10 V or higher | Place directly after the ferrite bead |
| 3 | Filtered 5 V ceramic capacitors | 100 nF, 0603 | One after the ferrite bead, one at `J_US1`, and one at `J_US2` |
| 4 | Local 100 nF ceramics | 0603, near Pico and level-shifter sections | Local logic decoupling |
| 1 | Pico bulk capacitor | 10 uF, 10 V or higher | Near the Pico power pins |
| 4 | BSS138 MOSFETs | One per HC-SR04 TRIG or ECHO path | Integrated 4-channel level shifter |
| 8 | Level-shifter pull-up resistors | 10 kOhm, 0603 | Four to 3.3 V and four to 5 V |
| 2 | HC-SR04 connectors | JST-XH 4-pin | `5V`, `TRIG`, `ECHO`, `GND` |
| 1 | LCD connector | JST-XH 12-pin | Main LCD harness |
| 1 | LCD contrast potentiometer | 10 kOhm trimmer | Generates `VO` locally |
| 1 | LCD backlight resistor footprint | 220 Ohm, 0603, populate only if the LCD module lacks its own resistor | Series limit for `LEDA` |
| 2 | Servo connectors | JST-VH 3-pin | Pan and tilt outputs |
| 1 | PDB auxiliary input connector | JST-VH 4-pin | `AUX_5V`, `SERVO_6V`, `GND`, `GND` |
| 1 | PDB motor-control connector | JST-XH 14-pin | Single low-current control harness |
| 1 | Filtered 5 V status LED plus resistor | 0603 LED plus 2.2 kOhm, 0603 | Confirms `5V_FILT` is present on the board |
| 1 | 3.3 V status LED plus resistor | 0603 LED plus 2.2 kOhm, 0603 | Confirms the Pico logic rail is alive |
| 8 | Test points | `AUX_5V`, `PICO_VSYS`, `USB_VBUS`, `5V_FILT`, `SERVO_6V`, `3V3`, `GND`, and one PWM line per side | Debug and scope access |

## Harness BOM

### Harness standards

- Standardize all board-side high-current connectors on JST-VH with vertical top-entry through-hole headers: `B2P-VH`, `B3P-VH`, and `B4P-VH`.
- Standardize all board-side signal connectors on JST-XH with right-angle side-entry through-hole headers: `S4B-XH-A`, `S12B-XH-A`, and `S14B-XH-A`.
- Standardize JST-VH harness contacts on `SVH-41T-P1.1`, which suits the chosen `18 AWG` and `20 AWG` stranded wire plan.
- Standardize JST-XH harness contacts on `SXH-001T-P0.6`, using `26 AWG` stranded wire for the HC-SR04 and LCD harnesses.
- Use `18 AWG` stranded wire for battery input, raw motor feed, and the four wheel-motor leads.
- Use `20 AWG` stranded wire for Raspberry Pi power, board-to-board auxiliary power, and both servo harnesses.
- Use `26 AWG` stranded wire for the HC-SR04, LCD, and PDB motor-control harnesses.

### Orientation and pin-1 rules

- All JST-VH board headers are vertical top-entry parts. Place them on the board edge with the mating face accessible from above the PCB.
- All JST-XH board headers are right-angle side-entry parts. Place them on the board edge so the cable exits parallel to the PCB and toward the enclosure wall, including the two 14-pin driver-control connectors.
- Mark pin 1 on every PCB footprint with a silkscreen triangle and keep the schematic pin order identical to the physical cavity order.
- For every power connector, pin 1 is the positive rail. For duplicated grounds, grounds follow after the positive rails.
- For every harness drawing, view pin order from the mating face of the cable housing, not from the wire-entry side.

### Board-side connector BOM

| Qty | Exact part | Series | Orientation | Used at |
| --- | --- | --- | --- | --- |
| 6 | `B2P-VH` | JST-VH | Vertical, top-entry, THT | `J_BAT`, `J_PI_PWR`, `J_MOTOR_FL`, `J_MOTOR_RL`, `J_MOTOR_FR`, `J_MOTOR_RR` |
| 2 | `B3P-VH` | JST-VH | Vertical, top-entry, THT | `J_SERVO_PAN`, `J_SERVO_TILT` |
| 2 | `B4P-VH` | JST-VH | Vertical, top-entry, THT | `J_CTRL_AUX`, `J_PWR_AUX` |
| 2 | `S4B-XH-A` | JST-XH | Right-angle, side-entry, THT | `J_US1`, `J_US2` |
| 1 | `S12B-XH-A` | JST-XH | Right-angle, side-entry, THT | `J_LCD` |
| 2 | `S14B-XH-A` | JST-XH | Right-angle, side-entry, THT | `J_CTRL_DRV`, `J_DRV_CTRL` |

### Harness-side connector BOM

This counts the board-mating housings and crimp contacts needed for one full robot build. Module-end terminations for the Raspberry Pi, LCD glass, HC-SR04 boards, and motor tabs stay separate from this count.

| Qty | Exact part | Series | Use |
| --- | --- | --- | --- |
| 6 | `VHR-2N` | JST-VH | Battery input, Raspberry Pi power, and four motor-output harnesses |
| 2 | `VHR-3N` | JST-VH | Two servo harnesses |
| 2 | `VHR-4N` | JST-VH | Board-to-board auxiliary power harness |
| 2 | `XHP-4` | JST-XH | HC-SR04 board-end housings |
| 1 | `XHP-12` | JST-XH | LCD board-end housing |
| 2 | `XHP-14` | JST-XH | Board-to-board driver-control harness |
| 26 | `SVH-41T-P1.1` | JST-VH | All VH crimp contacts for the board-mating cable ends |
| 48 | `SXH-001T-P0.6` | JST-XH | All XH crimp contacts for the board-mating cable ends |

### Off-board assembly parts

| Qty | Item | Suggested value or spec | Notes |
| --- | --- | --- | --- |
| 4 | Motor terminal suppression capacitors | 100 nF ceramic, X7R, 50 V or higher | Solder directly across each wheel-motor terminal pair with the shortest practical leads |

### Per-harness build list

| Harness | Qty | Board-side mating parts | Wire | Pin order |
| --- | --- | --- | --- | --- |
| Battery holder -> `J_BAT` | 1 cable | `1 x VHR-2N`, `2 x SVH-41T-P1.1` | `18 AWG` red and black | `1=VBAT`, `2=GND` |
| PDB `J_CTRL_AUX` -> control `J_PWR_AUX` | 1 cable | `2 x VHR-4N`, `8 x SVH-41T-P1.1` | `20 AWG` for all four conductors | `1=AUX_5V`, `2=SERVO_6V`, `3=GND`, `4=GND` |
| PDB `J_CTRL_DRV` -> control `J_DRV_CTRL` | 1 cable | `2 x XHP-14`, `28 x SXH-001T-P0.6` | `26 AWG` 14-conductor ribbon or bundled hookup wire | `1=GND`, `2=GP2/L_PWMA`, `3=GP3/L_AIN1`, `4=GP4/L_AIN2`, `5=GP5/L_BIN1`, `6=GP6/L_BIN2`, `7=GP7/L_PWMB`, `8=GND`, `9=GP8/R_PWMA`, `10=GP9/R_AIN1`, `11=GP10/R_AIN2`, `12=GP11/R_BIN1`, `13=GP12/R_BIN2`, `14=GP13/R_PWMB` |
| PDB `J_PI_PWR` -> Raspberry Pi power pigtail or adapter | 1 cable | `1 x VHR-2N`, `2 x SVH-41T-P1.1` | `20 AWG` red and black | `1=PI_5V`, `2=GND` |
| PDB `J_MOTOR_FL` -> front-left motor | 1 cable | `1 x VHR-2N`, `2 x SVH-41T-P1.1` | `18 AWG` pair | `1=A01`, `2=A02` |
| PDB `J_MOTOR_RL` -> rear-left motor | 1 cable | `1 x VHR-2N`, `2 x SVH-41T-P1.1` | `18 AWG` pair | `1=B01`, `2=B02` |
| PDB `J_MOTOR_FR` -> front-right motor | 1 cable | `1 x VHR-2N`, `2 x SVH-41T-P1.1` | `18 AWG` pair | `1=A01`, `2=A02` |
| PDB `J_MOTOR_RR` -> rear-right motor | 1 cable | `1 x VHR-2N`, `2 x SVH-41T-P1.1` | `18 AWG` pair | `1=B01`, `2=B02` |
| Control `J_SERVO_PAN` -> pan servo adapter lead | 1 cable | `1 x VHR-3N`, `3 x SVH-41T-P1.1` | `20 AWG` three-conductor | `1=PWM`, `2=SERVO_6V`, `3=GND` |
| Control `J_SERVO_TILT` -> tilt servo adapter lead | 1 cable | `1 x VHR-3N`, `3 x SVH-41T-P1.1` | `20 AWG` three-conductor | `1=PWM`, `2=SERVO_6V`, `3=GND` |
| Control `J_US1` -> forward-left HC-SR04 harness | 1 cable | `1 x XHP-4`, `4 x SXH-001T-P0.6` | `26 AWG` four-conductor | `1=5V`, `2=TRIG`, `3=ECHO`, `4=GND` |
| Control `J_US2` -> forward-right HC-SR04 harness | 1 cable | `1 x XHP-4`, `4 x SXH-001T-P0.6` | `26 AWG` four-conductor | `1=5V`, `2=TRIG`, `3=ECHO`, `4=GND` |
| Control `J_LCD` -> LCD harness | 1 cable | `1 x XHP-12`, `12 x SXH-001T-P0.6` | `26 AWG` 12-conductor ribbon or bundled hookup wire | `1=VSS`, `2=VDD`, `3=VO`, `4=RS`, `5=RW`, `6=E`, `7=D4`, `8=D5`, `9=D6`, `10=D7`, `11=LEDA`, `12=LEDK` |

### Practical notes

- Using JST-VH on the servo outputs means these become custom servo adapter leads, not direct mates to common hobby-servo plugs.
- Route the 14-pin JST-XH driver-control harness as a logic interconnect. Keep it separated from the four motor-output harnesses where practical instead of bundling it tightly alongside them over long runs.
- The HC-SR04 and LCD module ends are not standardized to JST footprints in this build. Terminate them with a dedicated adapter PCB or fixed pigtail as required by the module.
- Use `SVH-41T-P1.1` only with the specified `18 AWG` and `20 AWG` VH harnesses. Do not substitute `22 AWG` without changing the contact family.

## Notes

- No transformer is needed on either board. These are DC-to-DC buck stages, so the magnetic part is an inductor inside the regulator design or module.
- `0603` is the default only for the small passives. Bulk capacitors, trimmers, buck stages, fuse hardware, and the TB6612FNG thermal copper need larger packages and footprints.
- The PDB `DRV_3V3` rail and the control-board `3V3` rail are separate local rails. Connect the boards only through the defined grounds and the 14 control signals.
- The Pi 3B to motion-controller link stays on USB. No extra UART or USB-serial bridge is required for normal communication or programming; add SWD only if you want low-level debug access.
- Because the motor rail is raw 2S, verify wheel-motor stall current at full charge, not nominal battery voltage. The TB6612FNG is efficient enough that this matters.

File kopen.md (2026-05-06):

# Kopen

- USB-C to USB Micro cable
- 2x controller motor TB6612FNG
- Misschien wat STM32 chips?
- Chameleon Ultra v3 omdat dat cool is    
- Een nieuwe Pico 2 die ik kan solderen op m'n bord. Dan kan ik m'n LiPo 2 hergebruiken voor andere dingen. Audio heb ik al verhuisd naar m'n andere pico als geisoleerd component

## Kleine spullen?

“0603 resistor kit”
“0603 capacitor kit”
“JST connector kit”
“assorted LED kit”
“terminal block kit”

- 0603 resistor kit 1% 10 ohm–1M ohm
- 0603 MLCC capacitor kit
- JST-VH (2, 4, 6, 8, 12-16 pins)
- JST-XH  (straigth + right angle, male + female, breakaway strips)
- screw terminals: 2 and 3 pin
- ferrite beads - 600 Ω @ 100 MHz
- 100 nF ceramic caps

pfewww ik moet echt wel een hele baal dingen kopen om het mogelijk te maken :) leuk zo'n hobby project, vooral als je niet goed weet wat je aan 't doen bent. Maar god, hou vol, je leert er ontzettend veel van door te doen, dit moet uiteindelijk toch mogelijk zijn als ik elke dag een stukje werk uitvoert. Intertia gebruiken, zet jezelf in beweging zodat het makkelijker word om in beweging te blijven.

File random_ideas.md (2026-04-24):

# More ideas without priority

- consider robot vacuum wheel base instead of four wheels. Ask for other stable options and pros and cons
- camera image with Gemma 4 and that segmenting flow that can draw things o. Top of image would be cool
- teleoperated through iPhone with video would be fucking great. Especially if we allow multiple input controllers so we can use gamepad to the robot with video on phone.
- design firmware update architecture. The robot should expose one usbc port that we can connect to. The pi will accept update commands and will update the firmware of all microcontrollers. It should also be able to update itself. It should also be able to poll an update server to fetch updates so that logic needs to be separated.

## Documentation and schematics

- tsserial for custom PCB design (for instance, I'd like to have some kind of power board)

## Homekit support

UPDATE on the below!

Apple is now supporting matter protocol so we don't need custom homekit. This makes it easier to also integrate into other homekit like ecosystems. There's also a active rust crate using embassy for matter support:

https://github.com/sysgrok/rs-matter-embassy

We will adopt this instead of rebuilding hap-rs for no-std support. This also means we can have homekit/matter support on the host side without needing to maintain a custom hap-rs fork.

OLD:

the rust hap-rs crate is not really maintained anymore but might allow us to integate with homekit.

Maybe we can fork it, and transform it so we can use it with embassy as that does support async so the port would perhaps be doable? That would unlock rust in microcontrollers with no-std!!!

https://github.com/ewilken/hap-rs/issues/40

Either way, it would also be nice to have homekit support on the host side if thats the only feasible way at the moment. Its also perhaps less practical for my robot, although adding a flashlite to it would be cool, as well as having buttons on the robot that appears as switches is also cool.

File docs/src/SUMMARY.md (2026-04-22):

# Summary

[Introduction](introduction.md)

- [Architecture](architecture/architecture.md)
- [Protocol](architecture/protocol.md)
- [Hardware](hardware/index.md)
	- [Design](hardware/design.md)
	- [Components](hardware/components.md)
	- [Wiring](hardware/schematics/wiring.md)

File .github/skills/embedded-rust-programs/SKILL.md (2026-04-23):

---
name: embedded-rust-programs
description: "Hardware driver and firmware development best practices for embedded Rust"
---

# Embedded Rust Programs

Use this skill when designing or changing firmware control loops, board drivers, protocol-owned control state, or embedded-facing host abstractions.

## Core Pattern

Prefer one latest-wins desired-state owner for continuous control.

- The host or higher-level controller owns the desired state.
- The firmware owns the applied state and is the final safety authority.
- One-shot actions such as ping, logging, audio chunks, or parameter updates stay outside the continuous-control path.

For mortimmy, the default pattern is:

1. Build one explicit desired-control snapshot.
2. Clamp and validate it once.
3. Send it as an idempotent message.
4. Apply it through one firmware method.
5. Emit one acknowledgement telemetry type for that apply path.

## Typestate Guidance

Use typestate selectively.

- Use typestate for initialization, ownership transfer, and configuration sequences that should be impossible to misuse at compile time.
- Use runtime state machines for robot modes, autonomy plans, reconnect logic, and other behavior that must react to live inputs or telemetry.

If a state can legitimately change because of runtime events, it usually belongs in a runtime state machine, not in a typestate API.

## Driver And Firmware Rules

- Keep driver traits narrow and capability-oriented.
- Separate board-role features from peripheral and driver features.
- Let build and deploy tooling select supported feature bundles for each firmware image.
- Make invalid states hard to represent.
- Keep one apply path per control domain.
- Enforce limits in firmware even when the host clamps first.
- Validate build-time board selection when exactly one controller image should be produced.
- Prefer full desired-state snapshots over patch messages until payload size proves otherwise.
- Keep telemetry shaped around acknowledgement and observability, not around transport accidents.

## Review Checklist

- Is continuous control modeled as latest-wins state rather than a queue of imperative commands?
- Is there exactly one owner of desired state and one owner of applied state?
- Are safety limits enforced on the embedded side?
- Are runtime robot modes represented with explicit transitions?
- Is typestate only being used where compile-time guarantees actually help?
- Do tests cover roundtrip, latest-wins semantics, and timeout behavior?

## References

- See `reference/desired-control.md` for the mortimmy control pattern.
- See `reference/typestate.md` for when typestate helps and when it hurts.
- See `reference/state-machines.md` for runtime state-machine guidance.
- See `reference/driver-traits.md` for trait shape and design-contract rules.

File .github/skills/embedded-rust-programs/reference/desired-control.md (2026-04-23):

# Desired Control

Use this pattern for motion, servo targets, and other continuously refreshed control domains.

## Shape

- One owner of desired state on the host or controller side.
- One owner of applied state on the firmware side.
- One idempotent apply method in firmware.
- One acknowledgement telemetry type.

## Why It Works

- Latest-wins semantics are simple to reason about.
- Reordering and retries are safer because the full state is carried every time.
- Mixed input sources such as keyboard, autonomy, and future websocket clients can all target the same snapshot.
- Firmware timeout behavior is easier to define because control freshness is tied to one message family.

## Mortimmy Example

- Host owns desired mode, drive, and servo.
- Firmware applies that through `ControlLoop::apply_desired_state`.
- `Ping`, audio chunks, and parameter updates remain one-shot commands.

## Common Mistakes

- Using `Stop` as a synonym for `drive = 0`.
- Splitting one control domain across several independent wire commands.
- Letting host-side clamping replace firmware-side safety checks.
- Turning patches or deltas into the default format before measuring payload pressure.

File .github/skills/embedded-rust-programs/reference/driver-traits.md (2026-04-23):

# Driver Traits

Driver traits should expose capabilities, not board wiring details.

## Trait Shape

- Keep methods small and intention-revealing.
- Use shared units and domain types.
- Avoid catch-all methods with many optional parameters.
- Prefer idempotent setters or narrow commands over broad mutable bags of state.

## Design Contracts

Apply compile-time contracts where possible.

- Make capabilities explicit in the trait surface.
- Split traits when read and write responsibilities differ.
- Use newtypes and validated constructors for physical units and bounded values.

Apply runtime contracts where needed.

- Reject impossible hardware requests early.
- Re-clamp on the embedded side.
- Surface failures with domain errors instead of silent fallback.

This follows the embedded Rust design-contract guidance: use the type system to prevent misuse when practical, and keep runtime checks for the parts that genuinely depend on live hardware state.

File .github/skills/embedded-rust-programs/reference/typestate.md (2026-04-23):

# Typestate

Typestate encodes state in types so invalid transitions fail at compile time.

## Good Uses

- Peripheral initialization order.
- Builder-style setup that must consume one state to create another.
- Capability gating such as `ConfiguredUart`, `EnabledPwm`, or `UsbReady`.
- APIs where runtime misuse would be expensive, dangerous, or impossible to recover from.

## Bad Uses

- Live robot modes such as `Teleop`, `Autonomous`, or `Fault`.
- Autonomy plans that change because of timers, sensors, reconnects, or operator input.
- Control loops that must react to runtime telemetry.

## Rule Of Thumb

If a state changes because the outside world changes, prefer a runtime state machine.

This follows the embedded Rust book guidance: typestate is strongest when it enforces design contracts and configuration sequences, not when it tries to freeze dynamic behavior into compile-time types.

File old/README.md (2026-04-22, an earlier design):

# Building a 4WD Robot based on Arduino and Raspberry Pi

The goal of this project is to build a autonomous robot that can be expanded upon easily in software. The idea is to have a varietity of different sensors available from the start and build a nice looking casing around it.

## Update 20 April 2026!!

This has been 11 years since I've looked at the project. Times have changed and the advent of coding agents like GPT and Claude makes it easier to have multiple side-hobbies running. I will rebuild this whole project in Rust so I can learn low-level embedded programming and want to incorporate some of the advancements in AI to make it a more useful and fun robot.

I probably want to link this into my other hobby project [nexo](https://github.com/thiezn/nexo) that I'm working on to run models locally on my own hardware and provides a robust websocket API for inference and managing clients. 

My robot will then become another type of client to NEXO so it can do inference through my own setup. Moving all code to the old folder and starting fresh.

## Goals

- Autonomous driving robot
- Automatic object avoidance
- Facial recognition
- Video streaming
- Audio playback, Robot voice and music
- Voice control

## Hardware details

I've purchased the following initial hardware from the british site http://www.hobbycomponents.com/. It was the only site that I could find in Europe that had alot of the required components and had a lot of positive reviews. These parts will allow me to build the basic robot chassis for testing

- 1x Ultrasonic Module HC-SR04 Distance Sensor
- 2x L298N Stepper Motor Driver Controller Board WB291111
- 1x Hobby Components Arduino Compatible R3 Mega
- 1x V2 Mega Sensor Shield for Arduino
- 1x SG90 Pan & Titl servo bracket
- 2x Towerpro SG90 Micro servo 9g
- 1x 4 Wheeled Robot Smart Car Chassis Kit DC 3v 5v 6v suitable for Arduino
- 1x 20cm Solderless Female to Female DuPont Jumper Breadboard Wires (40-Cable Pack)

Next thing I need to take care of is the power supply. Initially I wanted to get a LiPo rechargable battery back with a USB circuit to recharge it. After some research I found out that I would need at least two LiPo backs in series (giving me 3.7x2 = 7.4V) but the available USB charger circuits would only work for single 3.7V packs. I decided on switching to LiPo 186500 batteries that I will install in a simple battery holder casing. I will have to remove the batteries from the holder to recharge them in a seperate charger. 

Purchasing batteries, a battery holder and battery charger in the Netherlands I found was very expensive. On recommendation from a collegue I placed an order at a chinese compagny called http://www.lightinthebox.com. I also purchased a bluetooth adapter and a ps3 compatible bluetooth controller that I want to use to remote control morTimmy the robot
- DIY 2-Slot 18650 Battery Holder with Pins – Black
- AC Charger + 2xUltraFire 18650 3.7V 3000mAh Rechargeable Battery with EU 100-240V Plug 
- Mini Bluetooth CSR V4.0 USB Dongle Adapter(Square)
- Rechargeable Bluetooth Wireless Controller for PS3 

The Raspberry Pi requires about 5V power and is sensitive to drops in voltage. Therefore to stabilise the voltage I decided to buy a so called UBEC. This is a switching voltage regulator that should be more efficient than the linear voltage regulator on the Raspberry Pi board itself. I purchased the following UBEC that came with pre-soldered micro-USB connector from the site http://dawnrobotics.co.uk
- 3A-6S UBEC for Raspberry Pi 'brand hobbywing'

My intention is to implement voice control and audio playback into morTimmy. The raspberry does provide an stereo output jack but unfortunately no audio input. Also the power the output jack can provide is very low so I decided to purchase a low-cost USB audio interface for http://www.dx.com.
- USB 2.0 Virtual 7.1 Channel Surround Sound Card Caleb (20cm-Cable)

The last bit on my hardware kit list is a camera. I would like to use openCV on the Raspberry Pi so decided to purchase the official Raspberry Pi Camera module and the most recent Raspberry Pi model 2B. This has a quad core processor which will allow me to use multiple threads on the different cores hopefully increasing performance dramatically over the previous Raspberry Pi models.
- Raspberry Pi 2B
- Raspberry Pi Camera Module rev 1.3

## Project progress

This section outlines the current status of my project. 

What have I done so far:
- Setup (this) github repository, first time working with git so bear with me!
- Created skeleton classes for both Arduino (C++) and the Raspberry Pi (Python)
- Starting to use Docstrings to properly document my code. Trying to follow the
  Google Style Python Docstrings guidelines. Also implemented sphinx on my 
  home server to generate documentation from the Docstrings. The documentation
  can be found in the relevant docs/ directories and on my personal
  homepage http://morTimmy.mortimer.nl/
- Received the hardware order I've placed with http://www.hobbycomponents.com/

### Images of build process
  Screenshot of hardware ordered from hobbycomponents.com

### Hard- and Software Interfaces schematic

The following schematic shows the various interfaces between the hardware and software components of morTimmy the Robot. Keep in mind that these will likely change over time as the project develops.

  ![morTimmy Interfaces schematics] (http://raw.github.com/thiezn/morTimmy/master/images/morTimmy_Interfaces.png)

## Credits

- First have to credit my wife for putting up with me and my time consuming hobbies!

- Next I have to really give credit to Miguel Grindberg. He has created a really excellent tutorial on 
  building an Arduino Robot. I especially like his detailed explanation and he uses a proper Object Oriented 
  structure in his project which allows you to easily expand upon the code. Check it out here: 

  http://blog.miguelgrinberg.com/post/building-an-arduino-robot-part-i-hardware-components

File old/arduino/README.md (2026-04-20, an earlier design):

#ARDUINO MEGA HARDWARE CONTROLLER FOR morTimmy the Robot

This is the code that will power the low level features of morTimmy the Robot. We will be using an Arduino Mega board to control various sensors, DC motors and Servo's. It will utilise a serial interface to communicate with the Raspberry Pi which will be responsible for handling the main program logic. The intention is to use OOB best practices to create a flexible programming environment.

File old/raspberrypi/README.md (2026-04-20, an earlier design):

#Raspberry Pi 'brains' for morTimmy the Robot

This is the code that will power the brain of morTimmy the Robot. The Raspberry Pi will utilise a serial connection with the Arduino to control the low level robotic features. In addition to that several external equipment like speakers, microphone and a camera will be connected directly to the Raspberry Pi.

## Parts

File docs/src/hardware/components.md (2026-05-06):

# Components

This section collects the concrete hardware parts currently used or evaluated for the robot. Each component page keeps its own notes, pinouts, and related images in a dedicated folder so the documentation stays grouped by part.

## Compute and control

- [Raspberry Pi 3B V1.2](components/raspberry-pi-3b/index.md): main host computer for orchestration, transport, and higher-level coordination.
- [Pico Audio Pack](components/pi-audio-hat/index.md): audio add-on mounted on the Pico 2 W.

## Power

- [Power System](components/power/index.md): finalized 2S battery, protection, and rail-generation plan for the power distribution board.

## Sensors and user interface

- [HC-SR04 Ultrasonic Sensor](components/hc-sr04/index.md): forward distance sensing.
- Adafruit 4-channel I2C-safe Bi-directional Logic Level Converter (BSS138): shared 3.3 V to 5 V signal translation for HC-SR04 TRIG/ECHO lines and future open-drain peripherals.
- [Liquid Crystal Display](components/liquid-crystal-display/index.md): 16x2 character display for local status output.

## Actuation

- [TB6612FNG Motor Driver](components/TB6612FNG%20motor%20driver/index.md): dual MOSFET H-bridge used for the left and right wheel-drive stages on the PDB.
- [L298N Stepper / Motor Driver](components/l298n-stepper-motor-driver/index.md): earlier prototype driver board kept for historical reference.
- [Motors](components/motors/index.md): current DC motor models used for the prototype.
- [Servos](components/servos/index.md): pan / tilt servo interface and power plan for the control board.

## Notes

- The current robot wiring is documented in [Wiring](schematics/wiring.md).
- The hardware design rationale is documented in [Design](design.md).

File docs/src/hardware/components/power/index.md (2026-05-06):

# Power System Design

The current electrical design uses a dedicated power distribution board fed from a 2S battery pack.

## Final board targets

- Battery input on a 2-pin JST-VH connector
- Protected raw battery rail `MOTOR_VM` for the two TB6612FNG stages
- 5.1 V buck output split into protected `PI_5V` for the Raspberry Pi and `AUX_5V` for the control board
- Dedicated `SERVO_6V` buck rail for the pan and tilt servos
- Local `DRV_3V3` rail on the PDB for TB6612FNG `VCC` and `STBY`
- Battery-entry bulk capacitance, per-driver `220 uF + 100 nF` motor decoupling, and dedicated Raspberry Pi output protection

## Prototype parts on hand

- DIY 2-Slot 18650 Battery Holder with Pins – Black
- AC Charger + 2xUltraFire 18650 3.7V 3000mAh Rechargeable Battery
- 3A-6S UBEC 'hobbywing' for powering the Raspberry Pi and stabilizing the voltage
- UBEC or equivalent buck module for the 6 V servo rail

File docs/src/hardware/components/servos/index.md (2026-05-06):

# Servos

The control board reserves two hobby-servo outputs for pan and tilt motion.

## Electrical interface

- `GP18` is reserved for the pan servo PWM signal.
- `GP19` is reserved for the tilt servo PWM signal.
- Both servos are powered from the dedicated `SERVO_6V` rail generated on the PDB.
- Servo ground must remain common with the motion-controller ground.

## Board-level wiring

| Control-board signal | Servo lead | Notes |
| --- | --- | --- |
| `GP18` | Pan servo PWM | Reserved in hardware; firmware support is not bound yet |
| `GP19` | Tilt servo PWM | Reserved in hardware; firmware support is not bound yet |
| `SERVO_6V` | `V+` | Dedicated servo rail kept separate from `AUX_5V` |
| `GND` | `GND` | Shared reference with the Pico and the PDB |

## Connector plan

- Use JST-VH 3-pin connectors on the control board.
- Build adapter leads from JST-VH to the final servo plug style.
- Keep servo power wiring separate from the low-current LCD and sensor harnesses.

## Notes

- The hardware reserves these outputs now even though the `board-motion-controller` firmware does not drive them yet.
- Servo surge current stays on the dedicated `SERVO_6V` rail and should not be taken from the logic 5 V path.

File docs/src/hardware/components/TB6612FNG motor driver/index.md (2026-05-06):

# TB6612FNG Motor Driver

This is the wheel-motor driver used by the current PCB design.

## Overview

The Toshiba TB6612FNG is a dual brushed-DC motor driver with two MOSFET H-bridges. It can drive two bidirectional DC motors or one bipolar stepper motor and is a much better fit for 3.3 V microcontrollers than the L298N. In this robot, two TB6612FNG stages sit on the power distribution board: one stage for the left wheels and one stage for the right wheels.

## Key characteristics

- Dual H-bridge for 2 DC motors or 1 bipolar stepper
- Recommended motor supply `VM`: 4.5 V to 13.5 V
- Logic supply `VCC`: 2.7 V to 5.5 V
- Continuous output current: about 1.0 A to 1.2 A per channel depending on carrier PCB and thermal design
- Peak output current: up to about 3.0 A to 3.2 A per channel for short bursts
- PWM control input up to 100 kHz
- MOSFET output stage with much lower voltage drop than the L298N
- Standby control, coast mode, short-brake mode, thermal shutdown, undervoltage lockout, and internal flyback diodes

## Pinout

| Signal | Function |
| --- | --- |
| `VM` | Motor supply input |
| `VCC` | Logic supply input |
| `GND` | Shared logic and motor ground |
| `STBY` | Enables the H-bridges when held high |
| `PWMA` | PWM speed command for channel A |
| `AIN1` / `AIN2` | Direction and brake control for channel A |
| `A01` / `A02` | Motor A outputs |
| `PWMB` | PWM speed command for channel B |
| `BIN1` / `BIN2` | Direction and brake control for channel B |
| `B01` / `B02` | Motor B outputs |

## How it is used in this project

Two TB6612FNG stages are mounted on the PDB, one stage for the left wheels and one stage for the right wheels. The motion-controller Pico drives both stages over a 14-pin JST-XH control harness carrying 12 motor-control signals plus 2 grounds.

Left-side stage:

- `GP2` -> `PWMA`
- `GP3` -> `AIN1`
- `GP4` -> `AIN2`
- `GP5` -> `BIN1`
- `GP6` -> `BIN2`
- `GP7` -> `PWMB`

Right-side stage:

- `GP8` -> `PWMA`
- `GP9` -> `AIN1`
- `GP10` -> `AIN2`
- `GP11` -> `BIN1`
- `GP12` -> `BIN2`
- `GP13` -> `PWMB`

Both stages use the local `DRV_3V3` rail on the PDB for `VCC`. The `STBY` input is pulled high on the PDB with a local pull-up and exposed as a test pad or solder jumper rather than consuming another Pico GPIO. The `VM` input is the protected raw 2S motor rail `MOTOR_VM`.

## Electrical notes

- The TB6612FNG drops far less voltage than the L298N. A 2S pack that felt acceptable through the L298N can overdrive nominal 6 V motors through the TB6612FNG.
- Confirm the real stall current of each motor at the chosen `VM` and keep it comfortably below the per-channel limit.
- Place one 100 nF ceramic directly at `VCC`, one 100 nF ceramic directly at `VM`, and one 220 uF low-ESR bulk capacitor on the `MOTOR_VM` rail near each driver stage.
- Fit one 100 nF ceramic directly across each wheel-motor terminal pair at the motor body.
- Keep motor-current loops short and wide. Route logic traces away from the motor outputs and return the driver grounds into a low-impedance ground region.

## Mechanical notes

- Place each driver stage on the PDB close to its motor connectors and the incoming `MOTOR_VM` entry point.
- Give each stage stitched ground copper, short motor traces, and direct access to its local `220 uF + 100 nF` decoupling parts.

## References used

- Toshiba TB6612FNG datasheet
- SparkFun TB6612FNG Hookup Guide
- Pololu TB6612FNG carrier specifications

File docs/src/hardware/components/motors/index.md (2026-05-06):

# Motors

Can't find the official specifications but it's likely close to or exactly this:

|Voltage| DC 3V|DC 5V|DC 6V|
|---|---|---|---|
|Current|100 MA|100MA|120MA|
|Reduction rate|48:1|48:1|48:1|
|RPM (With tire)|100|190|240|
|Tire Diameter (mm)|66|66|66|
|Car Speed(M/minute)|20|39|48|
|Motor Weight (g)|50|50|50|
|Motor Size (mm)|70x22x18|70x22x18|70x22x18|
|Noise|<65dB|<65dB|<65dB|

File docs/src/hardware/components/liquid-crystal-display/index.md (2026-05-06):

# Liquid Crystal Display

This came with the Arduino Starter Kit.

Model is LCM1602C V2.1

## Overview

This is a standard 16x2 character LCD module in the HD44780 family. I could not find a trustworthy public datasheet for the exact `LCM1602C V2.1` board revision, so the details below are based on common HD44780-compatible 1602 modules and line up with how the module is wired in the project schematic.

## Key characteristics

- 16 characters x 2 rows
- 5x8 dot matrix per character
- HD44780-compatible command set
- Supports 8-bit and 4-bit parallel modes
- Typical logic supply: 5 V
- Typical logic current: around 1 mA to 2 mA without backlight
- Backlight uses separate LED pins

## Pinout

| Pin | Name | Function |
| --- | --- | --- |
| 1 | VSS | Ground |
| 2 | VDD | +5 V logic supply |
| 3 | VO / VE | Contrast input, usually from a potentiometer wiper |
| 4 | RS | Register select, command or data |
| 5 | RW | Read or write, often tied to ground for write-only use |
| 6 | E | Enable strobe |
| 7 | D0 | Data bit 0 |
| 8 | D1 | Data bit 1 |
| 9 | D2 | Data bit 2 |
| 10 | D3 | Data bit 3 |
| 11 | D4 | Data bit 4 |
| 12 | D5 | Data bit 5 |
| 13 | D6 | Data bit 6 |
| 14 | D7 | Data bit 7 |
| 15 | LEDA | Backlight LED anode |
| 16 | LEDK | Backlight LED cathode |

## How it is used in this project

The display is wired in 4-bit write-only mode from the motion-controller Pico LiPo 2:

- `RS` is on `GP20`
- `E` is on `GP21`
- `D4` is on `GP22`
- `D5` is on `GP26`
- `D6` is on `GP27`
- `D7` is on `GP28`
- `RW` is tied to ground
- `D0` to `D3` are left unconnected
- `VO` is driven by a 10 kOhm contrast potentiometer
- `LEDA` and `LEDK` power the backlight

## Electrical notes

- Common operating range for these modules is about 4.7 V to 5.3 V
- Input high level is compatible with common 5 V LCD logic
- Contrast is normally adjusted with a potentiometer between 5 V and ground, with the wiper on `VO`
- Some modules include a backlight resistor on the PCB and some do not; if yours does not, add a series resistor on `LEDA`

## Mechanical notes

Typical 1602 modules are about 80 mm x 36 mm with a 16-pin 0.1 inch header footprint.

## References used

- Generic HD44780-compatible 16x2 LCD module references
- Components101 16x2 LCD pinout summary
- Futurlec 16x2 LCD technical data for a compatible module

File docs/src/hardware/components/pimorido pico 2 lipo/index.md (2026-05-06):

# Pimoroni Pico Lipo 2

https://shop.pimoroni.com/products/pimoroni-pico-lipo-2?variant=55447851729275

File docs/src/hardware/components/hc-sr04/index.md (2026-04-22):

# Ultrasonic Ranging Module HC - SR04

## Product features

Ultrasonic ranging module HC - SR04 provides 2cm - 400cm non-contact
measurement function, the ranging accuracy can reach to 3mm. The modules
includes ultrasonic transmitters, receiver and control circuit. The basic principle
of work:
(1) Using IO trigger for at least 10us high level signal,
(2) The Module automatically sends eight 40 kHz and detect whether there is a
pulse signal back.
(3) IF the signal back, through high level , time of high output IO duration is
the time from sending ultrasonic to returning.
Test distance = high level time × velocity of sound (340M/S) / 2,

## Wire connecting direct as following

- 5V Supply
- Trigger Pulse Input
- Echo Pulse Output
- 0V Ground

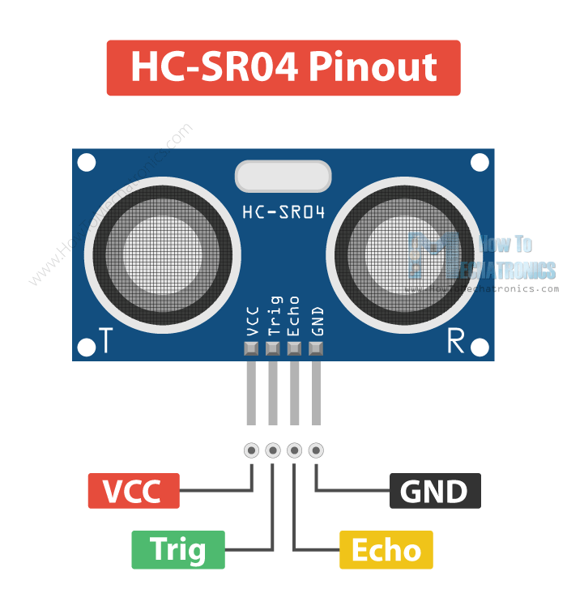
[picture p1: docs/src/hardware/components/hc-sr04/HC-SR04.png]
HC-SR04 pinout


## Electric Parameter

- Working Voltage: DC 5 V
- Working Current: 15mA
- Working Frequency: 40Hz
- Max Range: 4m
- Min Range: 2cm
- Measuring Angle: 15 degree
- Trigger Input Signal: 10uS TTL pulse
- Echo Output Signal: Input TTL lever signal and the range in proportion
- Dimension: 45*20*15mm

## Timing diagram

The Timing diagram is shown below. You only need to supply a short 10uS pulse to the trigger input to start the ranging, and then the module will send out an 8 cycle burst of ultrasound at 40 kHz and raise its echo. The Echo is a distance object that is pulse width and the range in proportion.

You can calculate the range through the time interval between sending trigger signal and receiving echo signal.

Formula: uS / 58 = centimeters or uS / 148 =inch; or: 
the range = high level time * velocity (340M/S) / 2

we suggest to use over 60ms measurement cycle, in order to prevent trigger signal to the echo signal.

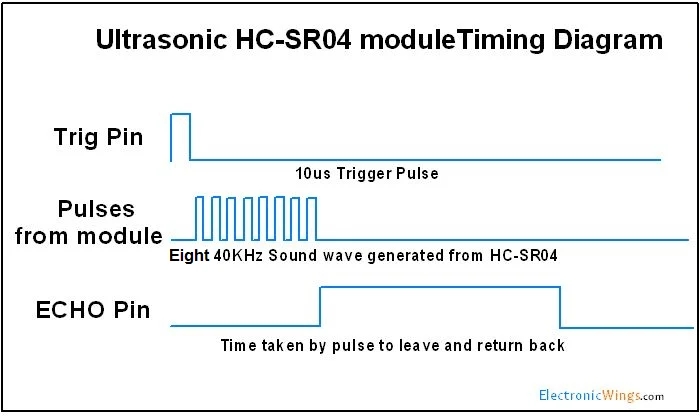
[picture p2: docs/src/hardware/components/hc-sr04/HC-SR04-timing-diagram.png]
Timing diagram


## Attention

The module is not suggested to connect directly to electric, if connected electric, the GND terminal should be connected the module first, otherwise, it will affect the normal work of the module. When tested objects, the range of area is not less than 0.5 square meters and the plane requests as smooth as possible, otherwise, it will affect the results of measuring.

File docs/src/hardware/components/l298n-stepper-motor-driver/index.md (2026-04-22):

# L298N DC Dual Motor Driver Circuit WB291111

WB291111 is a motor driver circuit with L298N motor driver IC. It can drive two dc motors or one 4-wire stepper motor. 

## Technical Specifications

- Driver chip: L298N Dual H-bridge driver chip
- Supply voltage VMS: +5 V - 35 V-
- Maximum current: 2A / bridge
- VSS Logic supply voltage: 4 .5-5 0.5 V
- Input Control Signal Voltage Range: H: 4.5 ~ 5.5V / L: 0V
- Maximum Power Consumption: 20W
- Working Temperature: -25℃ to 130℃
- Driver Board Size: 55mm * 60mm * 30mm
- Driver Board Weight: 33g
- Other Functions: Direction Control Indicator LED, Power Indicator LED

## Pin Connections

- ENA: Pin that activates the left motor channel.
- IN1 : Left engine 1st input
- IN2: Left engine 2nd input
- IN3: Right engine 1st input
- IN4: Right engine 2nd input
- ENB: Pin activating the right motor channel
- MotorA: Left motor output
- MotorB: Right motor output
- VMS: Supply voltage input ( 4.8V-24V)
- GND: Ground connection
- 5V: 5V output

- There are additionally jumper-mounted pins on the product There is also space. These pins work optionally and are required to activate different features.
- CSA: It is the current output of a motor driver channel. From here, the jumper can be removed and the current value can be read as analog voltage.
- CSB: B is the current output of the motor driver channel. The jumper can be removed from here and the current value can be read as analog voltage.
- V1: It is a jumper connected to the pull-up resistor that pulls the IN1 input directly to 5V. In this way, 5V will come to the ground unless you pull it - continuously.
- V2: It is a jumper connected to the pull-up resistor that pulls the IN2 input directly to 5V. In this way, 5V will come to the ground unless the pin pulls it - continuously.
- V3: It is a jumper connected to the pull-up resistor that pulls the IN3 input directly to 5V. In this way, 5V will come to the ground unless the pin pulls it - continuously.
- V4: It is a jumper connected to the pull-up resistor that pulls the IN4 input directly to 5V. In this way, 5V will come to the ground unless the pine draws - continuously.
- 5V-EN: Jumper that makes the 7805 line active and passive. The 5V output becomes active and 5V can be drawn from here. If you take it off, this hat will become inactive.

## Images

Image of my own L298N driver board

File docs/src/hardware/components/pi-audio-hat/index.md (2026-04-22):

# Pico Audio Pack

Pimoroni Pico Audio Pack is the audio add-on mounted on the Pico 2 W.

## Purpose

This board turns the Pico 2 W into the robot's audio controller. It accepts I2S digital audio from the Pico, converts it to analog audio, and exposes both line-level and headphone outputs.

## Main parts

- PCM5100A stereo DAC
- PAM8908JER stereo headphone amplifier
- AP7333-33SRG 3.3 V regulator
- 3.5 mm stereo line-out jack
- 3.5 mm stereo headphone jack
- Gain switch for the headphone amplifier

## Pin usage on the Pico

The Pico Audio Pack consumes the Pico's I2S pins.

| Pico GPIO | Audio Pack signal | Notes |
| --- | --- | --- |
| GP9 | I2S data / DIN | Serial audio data into the PCM5100A |
| GP10 | I2S bit clock / BCK / SCK | I2S clock |
| GP11 | I2S word select / LRCK / WS | Left-right channel clock |
| GP29 | MUTE / amp enable | Used by Pimoroni examples to silence or enable output |

The schematic and Pimoroni software examples both line up with this mapping. In example code, the pack is typically configured as `data=GP9`, `bclk=GP10`, and `lrck=GP11`.

## Wiring notes

- The board plugs directly onto the Pico header set.
- Audio is carried over I2S from the Pico to the DAC.
- The LCD in this project is placed on other spare Pico GPIO so GP9-GP11 remain reserved for audio.
- The board exposes analog output only; it is not a speaker power stage for large passive speakers.

## Capabilities

- Stereo DAC output up to 32-bit / 384 kHz according to the PCM5100A device used on the board
- Headphone output through the onboard amplifier
- Line-level output for an external amplifier or powered speakers

## Mechanical notes

- Approximate dimensions: 53 mm x 29 mm x 11 mm
- Designed as a Pico add-on pack with pre-soldered female headers

## Sources used

- Pimoroni product page
- Pimoroni Pico Audio Pack schematic PDF
- Pimoroni example code showing `GP9`, `GP10`, and `GP11` I2S usage

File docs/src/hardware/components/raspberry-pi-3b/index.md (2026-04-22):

# Raspberry Pi 3B V1.2

Released in 2015.

- Quad Core 1.2GHz Broadcom BCM2837 64bit CPU
- 1GB RAM
- BCM43438 wireless LAN and Bluetooth Low Energy (BLE) on board
- 100 Base Ethernet
- 40-pin extended GPIO
- 4 USB 2 ports
- 4 Pole stereo output and composite video port
- Full size HDMI®
- CSI camera port for connecting a Raspberry Pi camera
- DSI display port for connecting a Raspberry Pi touchscreen display
- Micro SD port for loading your operating system and storing data
- sUpgraded switched Micro USB power source up to 2.5A

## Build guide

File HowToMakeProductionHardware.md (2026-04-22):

# How To Make Production Hardware

What big components would i need to have after the breadboard/cable mess experiment is over?

This is a **very good instinct** and you’re hitting the point where hobby robots usually break down into spaghetti, while professional robots turn into *systems*. What you’re sensing (“this power stuff is a hodgepodge”) is exactly the signal to **change how you think about the robot**.

Below is how this is *typically* solved in robust robots, and how to reason about it cleanly.

I’ll walk through:

1.  **The correct abstraction model for a robot**
2.  **How power is handled professionally**
3.  **Power board vs motherboard vs backplane**
4.  **Interconnect strategy (connectors, buses)**
5.  **A staged path from breadboard → v1 robot → v2 “real” robot**
6.  **What *not* to do (common traps)**

## 1. The right mental model: robots are layered systems

Professional robots are *not* “a pile of electronics”. They are almost always decomposed like this:

    Mechanical
    └── Power
        ├── High-power actuation (motors)
        ├── Medium-power actuation (servos)
        ├── Logic power (MCUs, SBCs)
    └── Compute & Control
        ├── Brain (SBC / main computer)
        ├── Real-time controllers (MCUs)
    └── Interconnect
        ├── Power distribution
        ├── Data buses
    └── Peripherals
        ├── Sensors
        ├── Actuators
        ├── UI (audio, LEDs, buttons)

**Key insight**  
👉 Power is *not* an afterthought. It is its **own subsystem**, on equal footing with compute.

Once you internalize this, the mess starts to disappear.

## 2. How power is *actually* handled in sane robots

### The golden rule

> **No device generates its own voltage unless it absolutely must.**

Instead:

### Typical power architecture

    Battery (single source)
    │
    ├── High-current rail (raw / bucked)
    │   └── Motor drivers
    │
    ├── Medium-current rail (e.g. 6V)
    │   └── Servos
    │
    └── Logic rails
        ├── 5V → SBC, USB devices
        └── 3.3V → MCUs, sensors

### Why this matters

*   Motors inject **noise** and **voltage dips**
*   Servos cause **transient current spikes**
*   MCUs and SBCs are **sensitive and fragile**

So you deliberately **electrically separate concerns** while sharing a common ground (star-grounding or controlled ground planes).

## 3. Powerboard vs motherboard vs backplane (what to build?)

You basically have **three architectural options**. Engineers usually evolve through all three.

### Option A — Power Distribution Board (PDB) ✅ *Most common*

This is the **sweet spot** for robots like yours.

**What it is**

*   A custom PCB whose only job is:
    *   Take battery input
    *   Generate required voltages
    *   Distribute power cleanly
    *   Provide fusing and protection

**What it does NOT do**

*   No microcontroller
*   No logic
*   No high-level routing

**Typical contents**

*   Battery connector
*   Main fuse
*   Reverse polarity protection
*   Buck converters (e.g. 12V→6V, 12V→5V, 5V→3.3V)
*   Bulk capacitors
*   Connectors for:
    *   Motor power
    *   Servo power
    *   Logic power
    *   Ground returns

**Everything else plugs into it.**

> This is how *most* real robots start.

✅ Recommended for you as **v1 final system**

### Option B — Motherboard (integrated power + compute)

Used when:

*   Space is extremely constrained
*   You are building many units
*   You control *all* peripherals

**Downsides**

*   Design complexity explodes
*   You lose modularity
*   One mistake breaks everything

For a learning-focused robot: **not recommended initially**

### Option C — Backplane / bus board (modular, pro-level)

Think:

*   Robotics platforms
*   Industrial controllers
*   Space and automotive systems

**What it is**

*   A board with standardized connectors
*   Power + data distributed via slots
*   Modules plug in (motor card, sensor card, compute card)

**Power + data on the same connector**

*   CAN
*   RS-485
*   SPI
*   I²C (short runs)

This is **fantastic**, but it’s a **v2 or v3 move**, not v1.

## 4. How to structure interconnects cleanly

### Separate *power* from *signals*

This alone eliminates 80% of noise issues.

#### Power connectors

*   Motors: screw terminals / XT30 / XT60
*   Servos: 3-pin servo headers (GND / V+ / PWM)
*   Logic: JST, USB, or board headers

#### Data connectors

*   UART, CAN, I²C on separate headers
*   Never daisy-chain power through logic connectors if avoidable

### Use voltage rails by role, not by device

Bad:

    This Pico has its own regulator
    That board makes its own 5V
    This servo board injects noise everywhere

Good:

    One 5V rail
    One 6V rail
    One 3V3 rail
    Everything consumes, nothing regulates

## 5. A concrete architecture for *your robot*

### Logical block view

              ┌────────────────────┐
              │   Battery Pack     │
              └─────────┬──────────┘
                        │
              ┌─────────▼──────────┐
              │  POWER BOARD (PCB) │   ← your “anchor”
              │───────────────────│
              │  • Fuse            │
              │  • Reverse prot.   │
              │  • Buck 6V (servo) │
              │  • Buck 5V (logic) │
              │  • Buck/LD0 3V3    │
              └───┬──────┬──────┬─┘
                  │      │      │
          ┌───────▼───┐  │  ┌───▼────────┐
          │ Motor Ctrl │  │  │ Servo Rail │
          │   Pico     │  │  │ (headers)  │
          └───────────┘  │  └────────────┘
                          │
                   ┌──────▼──────┐
                   │ Raspberry Pi │
                   └─────────────┘

### Data interconnect

*   Pi ↔ Pico(s): USB or UART
*   Pico ↔ Sensors: direct GPIO / I²C
*   Audio Pico: USB or UART command channel

## 6. How professionals *arrive* at this system (important)

Nobody starts with a perfect powerboard.

### Typical evolution path

**Phase 1: Chaos (you are here)**

*   Breadboard
*   Random buck converters
*   Dupont wires
*   Things reset mysteriously

✅ This is normal.

**Phase 2: Harnessed chaos**

*   Still breadboards
*   But:
    *   One main battery
    *   One main ground bus
    *   Labeled rails
    *   Star grounding

✅ Great for experimentation.

**Phase 3: Power distribution PCB**

*   One clean board
*   Everything plugs in
*   Mechanical mounting planned

✅ This is where your robot becomes “real”.

**Phase 4: Modular backplane (optional)**

*   Only if you scale or iterate heavily

## 7. Design rules that separate toys from systems

These are worth memorizing:

1.  **No regulator cascades** unless intentional  
    (5V → onboard 5V → 3V3 → noise city)

2.  **Motors never share a rail with logic**

3.  **Servos get their own rail**

4.  **One ground, many branches**

5.  **Every rail must be measurable**

6.  **Every rail must be fuseable**

7.  **Connectors beat soldered wires**

8.  **PCBs beat breadboards for power**

## 8. What I’d recommend you do next (very concrete)

### Short term

*   Continue with breadboards
*   Label rails clearly
*   Separate:
    *   motor power
    *   servo power
    *   logic power

### Medium term (first “real” robot)

*   Design a **power distribution PCB**
*   No controllers on it
*   Only:
    *   battery in
    *   regulators
    *   connectors
*   Mount it as the *central* point in your 3D printed chassis

### Long term

*   Optional:
    *   integrate current sensing
    *   add CAN power + data bus
    *   modular motor boards

## Final reassurance

What you’re describing is **exactly how real robotic systems are built**:

*   Power as a first-class subsystem
*   Modular compute
*   Clean interconnects
*   Mechanical + electrical designed together

You’re thinking like a systems engineer already — you just haven’t *seen* the clean version yet.

If you want, next we can:

*   Sketch a **first power board feature list**
*   Define **standard connectors** you should use consistently
*   Or design a **v1 chassis layout** that enforces good wiring discipline

Just tell me which direction you want to go.

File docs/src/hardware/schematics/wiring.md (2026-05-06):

# Wiring schematics

The robot wiring diagram is generated from the WireViz source in `schematics/wiring/mortimmy.yml`.

The tables below separate the firmware-backed motion-controller wiring from the reserved servo pins that are not bound in firmware yet. The TB6612FNG motor allocation, ultrasonic pair, and LCD mappings are already fixed in the current design.

## Motion controller wiring

The motion-controller firmware image targets the Pimoroni Pico LiPo 2 and binds the motor, ultrasonic, and LCD wiring directly in [firmware/rp2350/src/runtime/motion.rs](../../../firmware/rp2350/src/runtime/motion.rs). The current code still names the motor backend after the older L298N driver, but the active GPIO allocation already matches one TB6612FNG stage per side on the PDB. The Pico reaches those driver stages through the 14-pin control harness described in [PCB designs](pcb.md), and the generated diagram below should stay in sync with that firmware pin map.

### Pico 2 power and USB link

The PCB design uses a Raspberry Pi Pico 2 module on the control board. Power it from the board `AUX_5V` rail into the Pico `VSYS` pin through a reverse-blocking ideal-diode stage. Do not feed the Pico from the control-board `3V3` rail, and do not tie `AUX_5V` directly to the Pico `VBUS` pin.

Keep the Raspberry Pi 3B connection as a native USB device link on the Pico USB connector:

- USB `D+` and `D-` carry the actual Pi to Pico communication.
- USB `GND` and shield remain bonded through the cable.
- Host `VBUS` from the Pi USB port still reaches the Pico USB connector so the Pico sees USB attach and supports normal programming.
- The reverse-blocking `AUX_5V` to `VSYS` path prevents that host `VBUS` from backfeeding the board `AUX_5V` rail.

No extra UART is required for normal Pi 3B communication or programming. Add SWD only if you want board-level debug access.

### TB6612FNG control wiring

Per side, the current firmware still uses six motor-control signals: two PWM outputs and four direction pins. That maps directly onto `PWMA`, `AIN1`, `AIN2`, `BIN1`, `BIN2`, and `PWMB`, so the TB6612FNG interface does not need a new Pico GPIO because `STBY` is pulled high locally on the PDB.

Left motor-driver stage:

| Pico LiPo 2 pin | Firmware role | TB6612FNG pin | Notes |
| --- | --- | --- | --- |
| GP2 | PWM slice 1 A | PWMA | Front-left speed command |
| GP3 | GPIO output | AIN1 | Front-left direction A |
| GP4 | GPIO output | AIN2 | Front-left direction B |
| GP5 | GPIO output | BIN1 | Rear-left direction A |
| GP6 | GPIO output | BIN2 | Rear-left direction B |
| GP7 | PWM slice 3 B | PWMB | Rear-left speed command |
| GND | Common ground | GND | Required reference between Pico and driver |

Right motor-driver stage:

| Pico LiPo 2 pin | Firmware role | TB6612FNG pin | Notes |
| --- | --- | --- | --- |
| GP8 | PWM slice 4 A | PWMA | Front-right speed command |
| GP9 | GPIO output | AIN1 | Front-right direction A |
| GP10 | GPIO output | AIN2 | Front-right direction B |
| GP11 | GPIO output | BIN1 | Rear-right direction A |
| GP12 | GPIO output | BIN2 | Rear-right direction B |
| GP13 | PWM slice 6 B | PWMB | Rear-right speed command |
| GND | Common ground | GND | Required reference between Pico and driver |

These 12 control signals plus two ground references form the 14-pin board-to-board harness between the control board and the PDB.

Local support wiring:

| Support net | TB6612FNG pin | Notes |
| --- | --- | --- |
| PDB local `DRV_3V3` rail | VCC | Local motor-driver logic supply on the PDB |
| `DRV_3V3` via local pull-up on the PDB | STBY | Hold high to enable the bridges; expose a test pad or solder jumper on the PDB for bring-up and fault isolation |
| Motor rail | VM | Feed from the dedicated motor power path; do not assume raw 2S is safe for nominal 6 V motors |
| GND | GND | Shared reference between Pico, driver stage, and motor power return |

Motor outputs:

| Driver stage | Output pair | Motor |
| --- | --- | --- |
| Left TB6612FNG | A01 / A02 | Front-left motor |
| Left TB6612FNG | B01 / B02 | Rear-left motor |
| Right TB6612FNG | A01 / A02 | Front-right motor |
| Right TB6612FNG | B01 / B02 | Rear-right motor |

### HC-SR04 wiring

The wiring plan uses two HC-SR04 modules mounted forward-left and forward-right at roughly 45 degrees. Both sensors share the single Adafruit 4-channel I2C-safe bi-directional logic level converter board. That breakout has four independent BSS138 channels with 10 kOhm pull-ups, plus shared `LV`, `HV`, and `GND` reference rails.

Shared rails:

| Control-board source | Level converter pin | HC-SR04 pin | Notes |
| --- | --- | --- | --- |
| 3V3 OUT (The + pin on our Pico) | LV | - | Required low-side reference for the BSS138 board |
| `5V_FILT` | HV | VCC on both sensors | Filtered 5 V rail for the HC-SR04 pair |
| GND | GND | GND on both sensors | Shared logic ground across Pico, converter, and both sensors |

Forward-left sensor:

| Pico LiPo 2 pin | Level converter pin | HC-SR04 pin | Notes |
| --- | --- | --- | --- |
| GP14 | LV1 | TRIG via HV1 | Forward-left trigger output |
| GP15 | LV2 via HV2 | ECHO | Forward-left echo input level shifted back to 3.3 V |

Forward-right sensor:

| Pico LiPo 2 pin | Level converter pin | HC-SR04 pin | Notes |
| --- | --- | --- | --- |
| GP16 | LV3 | TRIG via HV3 | Forward-right trigger output |
| GP17 | LV4 via HV4 | ECHO | Forward-right echo input level shifted back to 3.3 V |

This is a better fit than the earlier passive divider note because the converter needs both the Pico `3V3` rail and the sensor `5V` rail to operate.

With conservative level shifting on both `TRIG` and `ECHO`, the two HC-SR04 modules fully consume the four BSS138 channels on the Adafruit board. There are no spare shifted channels left for a third ultrasonic sensor in this wiring plan.

The motion-controller firmware now binds both sensors directly:

- `GP14` / `GP15` for the forward-left sensor
- `GP16` / `GP17` for the forward-right sensor

The firmware polls the two sensors sequentially rather than simultaneously so one module finishes its acoustic burst before the other starts.

### LCD1602 wiring

Because the TB6612FNG `STBY` signal is handled locally on the PDB rather than by an extra GPIO, the motor section still claims only `GP2` through `GP17` and the servo plan keeps `GP18` and `GP19` reserved. The Pico LiPo 2 still has exactly six free GPIO: `GP20`, `GP21`, `GP22`, `GP26`, `GP27`, and `GP28`. That is enough for the LCD in 4-bit write-only mode, so the display can live on the motion-controller Pico without colliding with the Audio Pack.

Main LCD data and control wiring:

| Control-board source / Pico GPIO | LCD pin | Notes |
| --- | --- | --- |
| `5V_FILT` | VDD | Filtered 5 V logic supply |
| GND | VSS | Common ground |
| GP20 | RS | Command or data select |
| GP21 | E | Enable strobe |
| GP22 | D4 | 4-bit data bus bit 0 |
| GP26 | D5 | 4-bit data bus bit 1 |
| GP27 | D6 | 4-bit data bus bit 2 |
| GP28 | D7 | 4-bit data bus bit 3 |

Supporting LCD wiring:

| Support path | LCD pin | Notes |
| --- | --- | --- |
| Contrast potentiometer wiper | VO | 10 kOhm trimmer between 5 V and ground |
| Ground | RW | Tied low for write-only mode |
| `5V_FILT` through onboard or external resistor | LEDA | Backlight anode |
| Ground | LEDK | Backlight cathode |

This uses the last six free motion-controller GPIO after the servo reservation, so there is no extra GPIO headroom left on that Pico once the LCD is wired.

### Pan / tilt servo wiring

The desired full end state keeps the two hobby servos on the motion controller, but it does not reuse the 5 V logic rail. The hardware design already reserves a dedicated 6 V servo rail, so the Pico LiPo 2 only needs to provide PWM plus a shared reference ground.

Servo signal wiring:

| Pico LiPo 2 pin | Reserved role | Servo lead | Notes |
| --- | --- | --- | --- |
| GP18 | PWM output | Pan servo signal | First free GPIO after the HC-SR04 pair; reserved for the pan axis |
| GP19 | PWM output | Tilt servo signal | Adjacent free GPIO reserved for the tilt axis |
| GND | Common ground | Ground on both servos | Must be common with the dedicated servo rail ground |

Servo power wiring:

| Power source | Servo lead | Notes |
| --- | --- | --- |
| Dedicated 6 V servo rail | V+ on both servos | Keep servo surge current off the 5 V logic rail |
| Shared ground | GND on both servos | Join the servo rail return and the Pico ground at the same reference |

The `board-motion-controller` firmware image does not bind `GP18` or `GP19` yet. These pins remain reserved for the chosen pan / tilt hardware end state so the already-working motor and ultrasonic wiring can remain stable while the servo runtime is added.

### motion-controller scope

The `board-motion-controller` firmware image owns wheel-motor control through the TB6612-compatible `GP2` through `GP13` interface, HC-SR04 ranging, and the local HD44780 LCD status display. Battery sensing is tracked separately and should not be wired back into the motion-controller capability set until the Pico LiPo 2 ADC path is verified. The `GP18` / `GP19` servo reservation above is the next hardware step, but those pins should stay electrically idle until the servo runtime is added.

## Audio controller wiring

The audio controller lives on the Pico 2 W and only drives the Pimoroni Pico Audio Pack.

### Pico Audio Pack wiring

The Pico Audio Pack is mechanically a full-board add-on, but it only consumes the Pico's I2S trio plus one optional mute / amp-enable control line.

| Pico 2 W pin | Audio Pack signal | Requirement | Notes |
| --- | --- | --- | --- |
| GP9 | DIN | Required | I2S audio data into the PCM5100A DAC |
| GP10 | BCK | Required | I2S bit clock |
| GP11 | LRCK / WS | Required | I2S word-select clock |
| GP29 | AMP_EN / MUTE | Optional but recommended | Used by Pimoroni examples and the driver scaffolding to mute or enable output |

The Pico only needs `GP9`, `GP10`, `GP11`, optional `GP29`, plus power and ground for the Audio Pack harness.

mortimmy wiring diagram

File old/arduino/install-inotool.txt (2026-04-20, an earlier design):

inotools allow you to compile and Arduino code. Here's a quick rundown on how to install it on a Raspberry Pi:

  sudo apt-get install python-configobj python-setuptools git python-jinja2 python-serial picocom

clone ino from github:

  mkdir ~/development/arduino
  cd ~/arduino/
  git clone git://github.com/amperka/ino.git

  cd ino
   (sudo or su)
    make install

Sometimes ino does not like the version string provided, cat the file  /usr/share/arduino/lib/version.txt , it should look something like  1:1.0.5+dfsg2-1
, backup the file and leave just  1.0.5.

Here's a sample of my .inorc file:

~/.inorc:

  [build]
  board-model = ATMega

  [upload]
  board-model = ATMega
  serial-port = /dev/ttyACM0

  [serial]
  serial-port = /dev/ttyACM0

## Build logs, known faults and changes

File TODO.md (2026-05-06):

# TODO

- Build kicad symbols and schematic for PCB. Separate Power and control sections

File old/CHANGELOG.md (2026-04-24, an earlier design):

567885d (HEAD, origin/master, master) ADDED INITIAL ARDUINO PROJECT FOLDER AND CODE
1a3eb2b Reworked hardware controller classes to try and get as much logic as we can in the generic parent class
aedcbec Adjusted sendCommand function to accept fixed byte sized command and data fields. These will be sent to the Arduino for processing
ffa2d13 INTRODUCED HARDWARE CONTROL SKELETON CLASS
f679590 Added initial .gitignore file. Using it for *.pyc files only at the moment
c8dc276 UPDATED PROJECT LAYOUT
d0a8d7a Added README.md file describing the project and renamed my bot to morTimmy
a47ee52 Added four motors to Robot class and adjusted run() to make the robot spin constantly
1273632 removed accidentally added file from project
7a75acc INTRODUCED MOTOR DRIVER SKELETONS
8fbb8cf Initial Commit
a0cb226 Initial Commit

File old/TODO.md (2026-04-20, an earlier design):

# TODO List

Too much to sum up at the moment, but lets try anyway...

- Write documentation 
- Document build process for others to follow 
- Learn about unit testing and write tests for all modules 
- Electronic prototyping 
- Programming device drivers for each arduino component 
- Programming raspberry PI <-> Arduino  interface 
- Designing and printing robot chassis 
- Assembling robot 
- Programming basic driving functions 
- Programming automatic object avoidance 
- Programming remote control through Raspberry Pi Web/REST interface 
- Programming basic audio handling (in/outgoing audio) 
- Programming basic video capture 
- Programming video webcam movement

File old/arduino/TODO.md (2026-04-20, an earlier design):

# TODO LIST FOR ARDUINO CONTROLLER

- Find a suitable CLI compiler for aruino that runs on the Raspberry Pi
  - The official can be used from https://github.com/arduino/Arduino/blob/ide-1.5.x/build/shared/manpage.adoc
  - http://inotool.org/ is another one that seems to be nice
- Find a vim plugin for Arduino syntax highlighting
- Program the shizzle out of the Arduino!

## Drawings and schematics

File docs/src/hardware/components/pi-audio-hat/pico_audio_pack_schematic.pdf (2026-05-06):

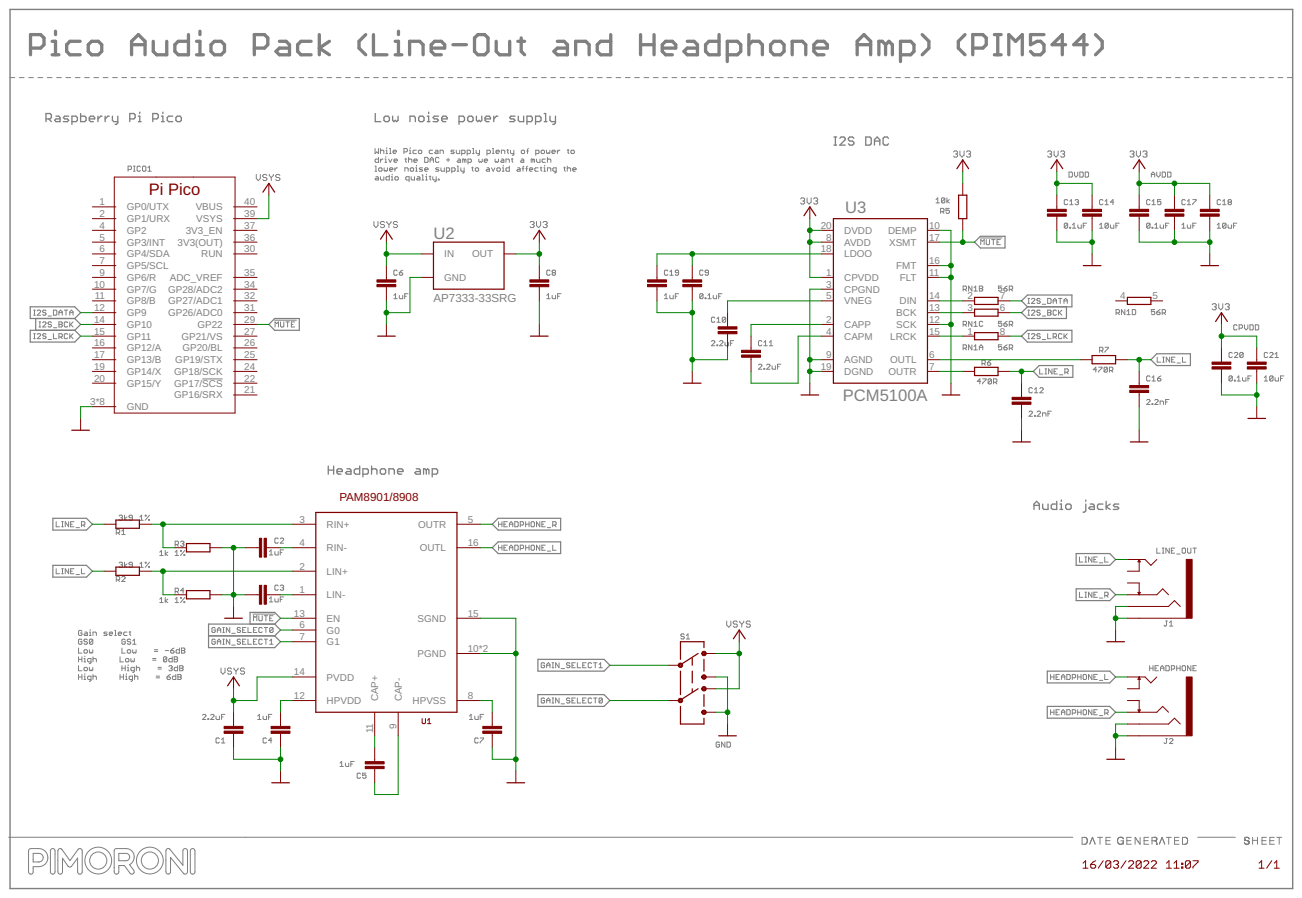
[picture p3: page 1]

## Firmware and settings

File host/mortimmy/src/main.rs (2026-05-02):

mod app;
mod audio;
mod brain;
mod camera;
mod cli;
mod config;
mod input;
mod nexo;
mod serial;
mod telemetry;
mod tui;
mod websocket;

use crate::cli::base::{Cli, Command};

#[tokio::main]
async fn main() -> anyhow::Result<()> {
    match Cli::parse_args().command {
        Command::Start(command) => app::start(command).await,
        Command::Test(command) => app::test(command).await,
        Command::Config(command) => app::configure(command),
    }
}

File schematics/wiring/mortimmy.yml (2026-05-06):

options:
  mini_bom_mode: false

connectors:
  BAT1:
    pinlabels: [ "B+", "B-" ]
    type: Battery holder
    subtype: 2x18650, 2S 7.4 V

  REG1:
    pinlabels: [ "VIN+", "VIN-", "VOUT+", "VOUT-" ]
    type: UBEC / buck
    subtype: 3A-6S in, 5 V 3 A out

  REG2:
    pinlabels: [ "VIN+", "VIN-", "VOUT+", "VOUT-" ]
    type: UBEC / buck
    subtype: 3A-6S in, 6 V servo rail out

  RPI_PWR:
    pinlabels: [ "5V_IN", "GND" ]
    type: Raspberry Pi 3B V1.2
    subtype: 5 V input

  RPI_USB_AUDIO:
    pinlabels: [ "VBUS", "D-", "D+", "GND", "SHELL" ]
    type: Raspberry Pi 3B V1.2
    subtype: USB host to audio

  RPI_USB_CTRL:
    pinlabels: [ "VBUS", "D-", "D+", "GND", "SHELL" ]
    type: Raspberry Pi 3B V1.2
    subtype: USB host to control

  PICO_AUDIO_USB:
    pinlabels: [ "VBUS", "D-", "D+", "GND", "SHELL" ]
    type: Pico 2 W
    subtype: USB device

  PICO_AUDIO_I2S:
    pinlabels: [ "GP9 DIN", "GP10 BCK", "GP11 LRCK", "GP29 AMP_EN", "PWR", "GND" ]
    type: Pico 2 W
    subtype: Audio Pack fly-lead breakout
    notes: Only these signals plus power and ground are needed when the Audio Pack
      is not stacked directly on the Pico.

  AUDIO_PACK1:
    pinlabels: [ "DIN", "BCK", "LRCK", "AMP_EN", "PWR", "GND" ]
    type: Pimoroni Pico Audio Pack
    subtype: PCM5100A DAC + headphone amp
    notes: If the pack is stacked directly on the Pico, this fly-lead harness
      collapses into the board-to-board header.

  PICO_CTRL_LCD:
    pinlabels:
      [
        "5V_FILT",
        "GP20 P26 RS",
        "GP21 P27 E",
        "GP22 P29 D4",
        "GP26 P31 D5",
        "GP27 P32 D6",
        "GP28 P34 D7",
        "GND P38",
      ]
    type: Pico LiPo 2
    subtype: LCD GPIO
    notes: These are the six remaining free GPIO once motors, the HC-SR04 pair, and
      the reserved GP18 and GP19 servo outputs are accounted for. The LCD 5 V
      supply shown here is the control-board `5V_FILT` rail, not Pico USB
      `VBUS`.

  PICO_CTRL_USB:
    pinlabels: [ "VBUS", "D-", "D+", "GND", "SHELL" ]
    type: Pico LiPo 2
    subtype: USB device
    notes: USB link to the Raspberry Pi 3B. Host `VBUS` stays on the USB connector
      for attach detect and programming, but the PCB powers the Pico from
      `AUX_5V` into `VSYS` through a reverse-blocking ideal-diode path.

  PICO_CTRL_LEFT:
    pinlabels:
      [
        "GP2 P4 PWMA",
        "GP3 P5 AIN1",
        "GP4 P7 AIN2",
        "GP5 P8 BIN1",
        "GP6 P10 BIN2",
        "GP7 P11 PWMB",
        "GND P9",
      ]
    type: Pico LiPo 2
    subtype: left GPIO

  PICO_CTRL_RIGHT:
    pinlabels:
      [
        "GP8 P12 PWMA",
        "GP9 P13 AIN1",
        "GP10 P14 AIN2",
        "GP11 P15 BIN1",
        "GP12 P16 BIN2",
        "GP13 P17 PWMB",
        "GND P18",
      ]
    type: Pico LiPo 2
    subtype: right GPIO

  PICO_CTRL_SENSOR:
    pinlabels:
      [
        "3V3 OUT",
        "5V_FILT",
        "GP14 P19 TRIG_LEFT",
        "GP15 P20 ECHO_LEFT",
        "GP16 P21 TRIG_RIGHT",
        "GP17 P22 ECHO_RIGHT",
        "GND P23",
      ]
    type: Pico LiPo 2
    subtype: ultrasonic GPIO
    notes: Two HC-SR04 modules share one 4-channel BSS138 level shifter. The sensor
      `HV` rail is the control-board `5V_FILT` net.

  PICO_CTRL_SERVO:
    pinlabels: [ "GP18 P25 PAN_PWM", "GP19 P26 TILT_PWM", "GND P24" ]
    type: Pico LiPo 2
    subtype: reserved pan / tilt servo GPIO
    notes: Reserved hardware servo PWM outputs. Not yet bound in motion-controller
      firmware.

  TB_LEFT_CTRL:
    pinlabels: [ "PWMA", "AIN1", "AIN2", "BIN1", "BIN2", "PWMB", "GND" ]
    type: TB6612FNG dual motor driver
    subtype: left control
    notes: One TB6612FNG stage drives the front-left and rear-left motors. VCC and
      STBY stay local on the PDB driver-logic rail.

  TB_LEFT_PWR:
    pinlabels: [ "VM", "GND" ]
    type: TB6612FNG dual motor driver
    subtype: left power
    notes: Motor supply only. VM is the protected raw motor rail. VCC and STBY are
      generated locally on the PDB.

  TB_LEFT_OUT:
    pinlabels: [ "A01", "A02", "B01", "B02" ]
    type: TB6612FNG dual motor driver
    subtype: left outputs

  TB_RIGHT_CTRL:
    pinlabels: [ "PWMA", "AIN1", "AIN2", "BIN1", "BIN2", "PWMB", "GND" ]
    type: TB6612FNG dual motor driver
    subtype: right control
    notes: One TB6612FNG stage drives the front-right and rear-right motors. VCC and
      STBY stay local on the PDB driver-logic rail.

  TB_RIGHT_PWR:
    pinlabels: [ "VM", "GND" ]
    type: TB6612FNG dual motor driver
    subtype: right power
    notes: Motor supply only. VM is the protected raw motor rail. VCC and STBY are
      generated locally on the PDB.

  TB_RIGHT_OUT:
    pinlabels: [ "A01", "A02", "B01", "B02" ]
    type: TB6612FNG dual motor driver
    subtype: right outputs

  MOTOR_FL:
    pinlabels: [ "+", "-" ]
    type: DC gear motor
    subtype: front-left

  MOTOR_RL:
    pinlabels: [ "+", "-" ]
    type: DC gear motor
    subtype: rear-left
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

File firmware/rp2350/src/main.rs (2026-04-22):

#![cfg_attr(all(target_arch = "arm", target_os = "none"), no_std)]
#![cfg_attr(all(target_arch = "arm", target_os = "none"), no_main)]

#[cfg(all(target_arch = "arm", target_os = "none"))]
#[embassy_executor::main]
async fn main(spawner: embassy_executor::Spawner) {
    mortimmy_rp2350::run(spawner).await
}

#[cfg(not(all(target_arch = "arm", target_os = "none")))]
fn main() {
    mortimmy_rp2350::run_host_stub();
}

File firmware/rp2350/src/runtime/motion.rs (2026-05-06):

#![allow(dead_code)]

#[cfg(feature = "sensor-ultrasonic")]
use embassy_rp::gpio::Input;
#[cfg(feature = "driver-l298n")]
use embassy_rp::pwm::Pwm;
use embassy_rp::{
    Peripherals,
    gpio::{Level, Output},
};
use embassy_time::{Delay, Instant};
use mortimmy_core::CoreError;
#[cfg(feature = "ui-display")]
use mortimmy_core::Mode;
#[cfg(feature = "ui-display")]
use mortimmy_drivers::{CharacterDisplay, Hd44780Lcd1602};
#[cfg(feature = "sensor-ultrasonic")]
use mortimmy_drivers::{HcSr04, HcSr04Error, MicrosecondClock, UltrasonicSensor};
#[cfg(feature = "driver-l298n")]
use mortimmy_drivers::{L298nBridge, L298nDriveMotorDriver, L298nSideDriver, MotorDriver};
use mortimmy_protocol::messages::telemetry::{RangeSensorPosition, RangeTelemetry};

#[cfg(not(feature = "driver-l298n"))]
use crate::runtime::NoopRuntimeHardware;
#[cfg(feature = "ui-display")]
use crate::ui::display::{DisplayFrame, render_motion_controller_frame};
use crate::{
    FirmwareScaffold,
    runtime::{BoardRuntime, RuntimeHardware},
};

const MOTION_USB_PRODUCT: &str = "mortimmy motion controller";
const MOTION_USB_SERIAL: &str = "mortimmy-motion-controller";

#[cfg(feature = "ui-display")]
type MotionLcd = Hd44780Lcd1602<
    Output<'static>,
    Output<'static>,
    Output<'static>,
    Output<'static>,
    Output<'static>,
    Output<'static>,
    Delay,
>;

#[cfg(feature = "sensor-ultrasonic")]
const ULTRASONIC_POLL_INTERVAL_US: u32 = 60_000;
#[cfg(feature = "sensor-ultrasonic")]
const ULTRASONIC_LOG_DELTA_MM: u16 = 100;

#[cfg(feature = "sensor-ultrasonic")]
#[derive(Clone, Copy, Debug, Default)]
struct EmbassyMicrosecondClock;

#[cfg(feature = "sensor-ultrasonic")]
impl MicrosecondClock for EmbassyMicrosecondClock {
    fn now_micros(&mut self) -> u32 {
        Instant::now().as_micros() as u32
    }
}

#[cfg(feature = "driver-l298n")]
struct MotionDriveHardware<Driver, Ultrasonic = ()> {
    driver: Driver,
    #[cfg(feature = "sensor-ultrasonic")]
    ultrasonic: Ultrasonic,
    #[cfg(feature = "sensor-ultrasonic")]
    last_ultrasonic_poll_micros: u32,
    #[cfg(feature = "ui-display")]
    display: MotionLcd,
    #[cfg(feature = "ui-display")]
    last_display_frame: Option<DisplayFrame>,
}

#[cfg(feature = "driver-l298n")]
impl<Driver, Ultrasonic> MotionDriveHardware<Driver, Ultrasonic> {
    fn new(
        driver: Driver,
        #[cfg(feature = "sensor-ultrasonic")] ultrasonic: Ultrasonic,
        #[cfg(feature = "ui-display")] display: MotionLcd,
    ) -> Self {
        Self {
            driver,
            #[cfg(feature = "sensor-ultrasonic")]
            ultrasonic,
            #[cfg(feature = "sensor-ultrasonic")]
            last_ultrasonic_poll_micros: 0,
            #[cfg(feature = "ui-display")]
            display,
            #[cfg(feature = "ui-display")]
            last_display_frame: None,
        }
    }

    #[cfg(feature = "ui-display")]
    fn sync_display(&mut self, scaffold: &FirmwareScaffold) {
        let frame = render_motion_controller_frame(scaffold.control.mode);

        if self.last_display_frame.as_ref() == Some(&frame) {
            return;
        }

        let _ = self.display.write_line(0, frame.line0.as_str());
        let _ = self.display.write_line(1, frame.line1.as_str());
        self.last_display_frame = Some(frame);
    }
}

#[cfg(all(feature = "driver-l298n", not(feature = "sensor-ultrasonic")))]
impl<Driver> RuntimeHardware for MotionDriveHardware<Driver>
where
    Driver: MotorDriver,
{
    fn sync_with_scaffold(&mut self, scaffold: &mut FirmwareScaffold) -> Result<(), ()> {
        if scaffold
            .control
            .drive
            .apply_to_driver(&mut self.driver, scaffold.control.limits.max_drive_pwm)
            .is_err()
        {
            defmt::warn!("motion drive hardware sync failed");
            self.enter_fault_state(scaffold, Some(CoreError::InvalidCommand));
            return Err(());
        }

        #[cfg(feature = "ui-display")]
        self.sync_display(scaffold);

        Ok(())
    }

    fn enter_fault_state(&mut self, scaffold: &mut FirmwareScaffold, error: Option<CoreError>) {
        scaffold.enter_fault_state(error);

        if self.driver.stop_all().is_err() {
            defmt::warn!("motion drive hardware stop failed");
        }

        #[cfg(feature = "ui-display")]
        self.sync_display(scaffold);
    }
}

#[cfg(all(feature = "driver-l298n", feature = "sensor-ultrasonic"))]
impl<Driver, UltrasonicLeft, UltrasonicRight, TriggerError, EchoError>
    MotionDriveHardware<Driver, (UltrasonicLeft, UltrasonicRight)>
where
    Driver: MotorDriver,
    UltrasonicLeft: UltrasonicSensor<Error = HcSr04Error<TriggerError, EchoError>>,
    UltrasonicRight: UltrasonicSensor<Error = HcSr04Error<TriggerError, EchoError>>,
{
    fn poll_ultrasonic(&mut self, scaffold: &mut FirmwareScaffold) {
        let now_micros = Instant::now().as_micros() as u32;
        if now_micros.wrapping_sub(self.last_ultrasonic_poll_micros) < ULTRASONIC_POLL_INTERVAL_US {
            return;
        }

        self.last_ultrasonic_poll_micros = now_micros;
        scaffold.sensors.ultrasonic.enabled = true;

        let (forward_left, forward_right) = &mut self.ultrasonic;
        poll_ultrasonic_sensor(RangeSensorPosition::ForwardLeft, forward_left, scaffold);
        poll_ultrasonic_sensor(RangeSensorPosition::ForwardRight, forward_right, scaffold);
    }
}
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

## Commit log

2026-04-22 big initial refactor. got rust firmware for pico, a brain with keyboard input, a protocol, working connectivity between brain and pico
2026-04-23 Implemented hardware drivers, tightened modes, protocol and documentation
    [autonomy.rs, codec.rs]
2026-04-26 Added back keyboard riving and some tweaks for reading ultrasonic sensor
2026-05-02 Fix drive keys after switching tui
    [l298n.rs, main.rs, mod.rs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]
2026-05-03 Got motor controllers working although IN2 of the left controller is broken. I need a new motor controller. Updated wiring to have two ultrasonic connected to the pico so we can slightly angle them a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
    [codec.rs, lib.rs, mod.rs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]
2026-05-03 Commit before refactoring protocol into sensor and desired state stream
2026-05-06 Starting with kicad schematics. Moving LCD to motion controller pico so audio is only present on the pico 2 w. We can just plug that in to the brain with USB and don't need to model anything on the P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
    [mortimmy.kicad_pcb, mortimmy.kicad_sch]
2026-05-06 exclude kicad history
2026-05-06 commit before refactoring wiring to use the TB6612FNG motor controllers.
    [mortimmy.kicad_pcb, mortimmy.kicad_sch]
2026-05-06 created pbd design document with detailed BOM and other stuff. Its maybe too professional for just a hobby priject and learning. probably will never get built but lets just try to get there slowly
